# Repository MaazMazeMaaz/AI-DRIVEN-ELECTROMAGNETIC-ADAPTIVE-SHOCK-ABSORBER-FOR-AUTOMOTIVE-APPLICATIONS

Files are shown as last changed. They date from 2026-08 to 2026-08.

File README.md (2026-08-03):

# AI-Driven Electromagnetic Adaptive Shock Absorber for Automotive Applications

# Project Gallery

---

| Prototype | AI Detection |
| --- | --- |
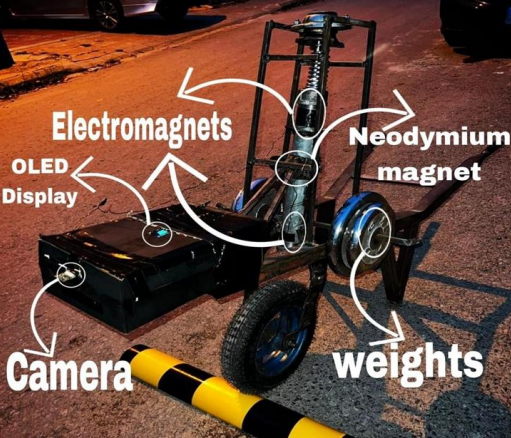
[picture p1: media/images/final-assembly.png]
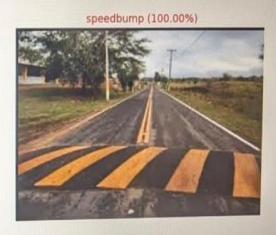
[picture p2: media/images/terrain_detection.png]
|  |  |

| CAD Model | Experimental Setup |
| --- | --- |
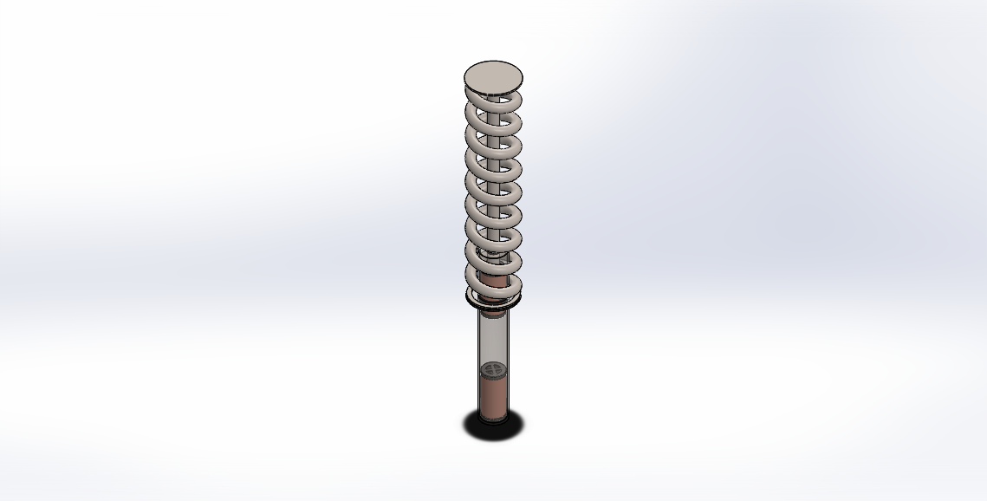
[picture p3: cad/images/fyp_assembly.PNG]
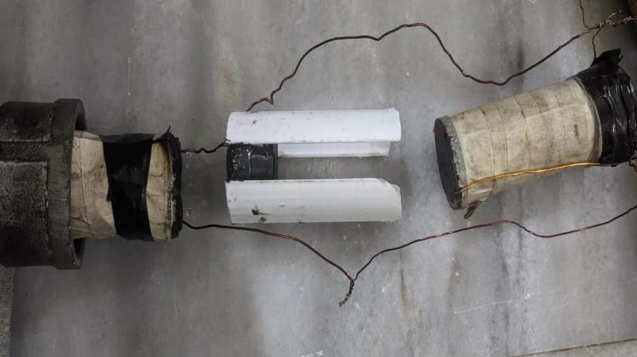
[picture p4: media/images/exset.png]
|  |  |

| Circuit Software | Experimental Circuit Hardware |
| --- | --- |
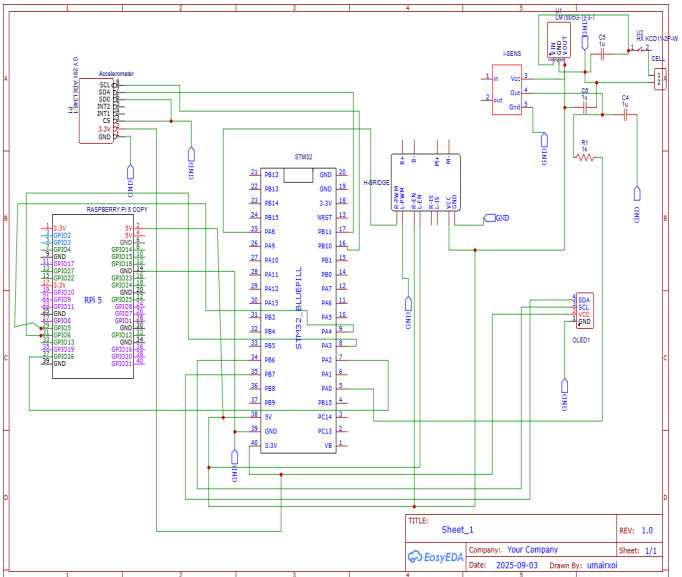
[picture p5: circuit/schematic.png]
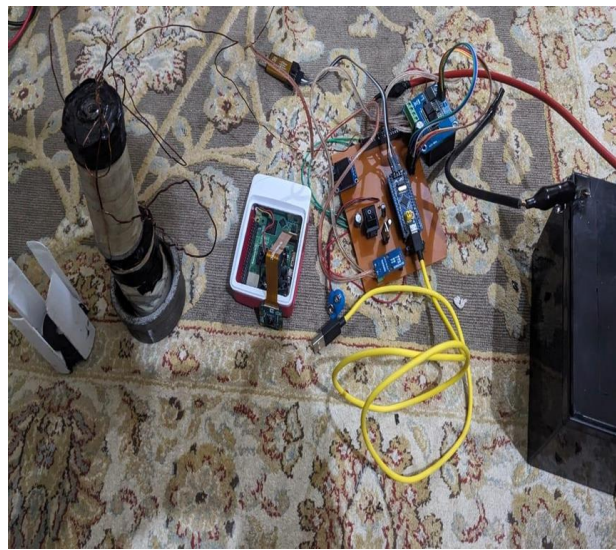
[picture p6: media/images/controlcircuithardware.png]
|  |  |
  










---

## Overview

Traditional hydraulic shock absorbers provide fixed damping characteristics regardless of road conditions, forcing engineers to compromise between ride comfort and vehicle handling. This project presents an **AI-driven electromagnetic adaptive shock absorber** capable of adjusting its damping characteristics in real time according to the terrain ahead.

The proposed system integrates computer vision, embedded control, electromagnetic actuation, and mathematical modelling into a single intelligent suspension framework. A Raspberry Pi 5 equipped with a camera performs real-time terrain classification using a trained YOLOv8 model. The detected terrain class is transmitted to an STM32F103 microcontroller, which dynamically regulates the current supplied to custom-designed electromagnets. The varying magnetic force modifies the damping characteristics of the suspension, enabling improved comfort and stability across different driving surfaces.

The project combines mechanical design, finite element simulation, artificial intelligence, embedded systems, and control engineering to demonstrate an adaptive suspension prototype suitable for future intelligent automotive systems.

---

## Key Features

* AI-based terrain classification using YOLOv8
* Real-time terrain recognition on Raspberry Pi 5
* Adaptive damping using electromagnets
* STM32-based embedded control system
* PWM current regulation through IBT-2 H-Bridge
* Closed-loop control using MPU6050 feedback
* Custom electromagnet design using MATLAB
* CAD modelling using SolidWorks
* Electromagnetic simulations using ANSYS Maxwell
* Modular hardware architecture for future automotive integration

---

## System Architecture

```
                Camera
                   │
                   ▼
        Raspberry Pi 5 (YOLOv8)
                   │
         Terrain Classification
                   │
               GPIO Signal
                   │
                   ▼
          STM32F103 Blue Pill
                   │
      PWM Current Control Logic
                   │
                   ▼
        BTS7960 / IBT-2 H-Bridge
                   │
                   ▼
        Electromagnetic Actuator
                   │
          Variable Damping Force
                   │
                   ▼
          Shock Absorber Assembly

          ▲
          │
 MPU6050 Accelerometer Feedback
```

---

## Project Objectives

The primary objectives of this project include:

* Develop an AI-based terrain classification system capable of recognizing asphalt, gravel, and speed bumps.
* Design an adaptive electromagnetic shock absorber capable of modifying damping characteristics in real time.
* Integrate computer vision with embedded control hardware.
* Develop mathematical models for electromagnet optimisation.
* Validate the proposed design using simulations and prototype testing.

---

## Technologies Used

### Artificial Intelligence

* YOLOv8 Classification
* Python
* OpenCV
* Ultralytics

### Embedded Systems

* Raspberry Pi 5
* STM32F103 Blue Pill
* UART Communication
* PWM Control

### Electronics

* BTS7960 (IBT-2) H-Bridge
* ACS712 Current Sensor
* MPU6050 Accelerometer
* LM7805 Voltage Regulator

### Mechanical Design

* Electromagnet Design
* Hydraulic Shock Absorber Modification
* Floating Permanent Magnet
* Custom Prototype Fabrication

### Engineering Software

* MATLAB
* SolidWorks
* ANSYS Maxwell
* Arduino IDE
* STM32CubeProgrammer

---

## Repository Structure

```
AI-Driven-Electromagnetic-Adaptive-Shock-Absorber
│
├── ai-terrain-classification/
│   ├── inference/
│   ├── training/
│   ├── results/
│   └──  best.pt
│
├── embedded/
│   ├── RaspberryPi/
│   └──  STM32/
│
├── matlab/
│
├── cad/
│
├── circuit/
│
├── modeling and simulations/
│
├── docs/
│
└── media/
```
---

# Hardware Components

| Component | Purpose |
| --- | --- |
| Raspberry Pi 5 | Runs the YOLOv8 terrain classification model |
| Raspberry Pi Camera V2 (8 MP) | Captures real-time road images |
| STM32F103 Blue Pill | Controls adaptive damping logic |
| IBT-2 (BTS7960) H-Bridge | Drives the electromagnets using PWM |
| ACS712 30A Current Sensor | Measures electromagnet current |
| MPU6050 Accelerometer | Provides stroke velocity and position feedback |
| LM7805 Voltage Regulator | Regulates power for electronics |
| 12V Battery | Main power source |
| Custom Electromagnets | Generate variable magnetic damping |
| Floating Neodymium Magnet | Provides repulsive magnetic force |
| Modified Shock Absorber | Mechanical suspension prototype |

---

# Software Stack

### Artificial Intelligence

* Python
* Ultralytics YOLOv8
* OpenCV
* NumPy

### Embedded Development

* Arduino IDE
* STM32 Arduino Core
* STM32CubeProgrammer

### Engineering Software

* MATLAB
* SolidWorks
* ANSYS Maxwell

---

# AI Terrain Classification

The perception module of the system is implemented on a **Raspberry Pi 5** using a YOLOv8 image classification model trained to recognize three road conditions:

* Asphalt
* Gravel
* Speed Bump

The Raspberry Pi continuously captures images from the Pi Camera and performs inference in real time. Once a terrain class is identified, the predicted class is transmitted  to the STM32 microcontroller.

Unlike conventional suspension systems that only react after encountering a disturbance, this approach enables **predictive damping control**, allowing the suspension to prepare before the vehicle reaches the detected terrain.

---

# Adaptive Damping Control

The STM32F103 Blue Pill serves as the real-time control unit.

After receiving the terrain classification from the Raspberry Pi, it adjusts the PWM duty cycle driving the BTS7960 H-Bridge.

Different terrains require different damping characteristics.

| Terrain | Control Strategy |
| --- | --- |
| Asphalt | Minimum or zero electromagnet current |
| Gravel | Medium current for moderate damping |
| Speed Bump | High current for maximum damping |

The MPU6050 accelerometer continuously measures piston movement and stroke velocity, allowing the controller to adjust damping dynamically during operation.

---

# Electromagnet Design

The damping mechanism replaces conventional passive damping with magnetic repulsion.

The prototype consists of:

* Two custom-designed electromagnets
* Soft iron cores
* Copper wire windings
* Floating neodymium magnet
* Hydraulic shock absorber body

Electromagnet dimensions were obtained through analytical calculations and optimized using MATLAB before validation in ANSYS Maxwell.

The final design balances:

* Magnetic force
* Current consumption
* Coil resistance
* Wire gauge
* Air gap
* Physical size constraints

---

# MATLAB Modelling

Several mathematical models were developed to optimize the electromagnet design, including:

* Magnetic force calculations
* Coil turn optimization
* Wire gauge selection
* Air-gap analysis
* Current limitation
* Saturation analysis
* Fringing correction
* Coil resistance estimation

MATLAB simulations were used to determine the optimum electromagnet geometry while satisfying mechanical constraints imposed by the modified shock absorber.

---

# ANSYS Maxwell Simulation

Finite Element Analysis (FEA) was performed using ANSYS Maxwell to validate the analytical calculations.

Simulation objectives included:

* Magnetic flux distribution
* Fringing effects
* Core saturation
* Field intensity
* Electromagnetic force validation

Simulation results closely matched the theoretical calculations and confirmed the suitability of the proposed electromagnet design.

---

# CAD Design

The complete suspension prototype was designed in SolidWorks.

The CAD model includes:

* Shock absorber cylinder
* Electromagnets
* Floating permanent magnet
* Mechanical spring
* Piston assembly
* Structural supports

The CAD model ensured correct fitment before fabrication and served as the basis for prototype manufacturing.

---

# Experimental Setup

The experimental platform consists of three primary subsystems.

### 1. Sensing

* Raspberry Pi 5
* Pi Camera

Responsible for real-time terrain perception.

---

### 2. Control

* STM32F103 Blue Pill
* MPU6050
* ACS712

Responsible for adaptive current regulation.

---

### 3. Actuation

* IBT-2 H-Bridge
* Electromagnets
* Floating Magnet
* Shock Absorber

Responsible for generating adaptive damping forces based on terrain classification.

---

# System Workflow

```text
Road Surface
      │
      ▼
Pi Camera
      │
      ▼
YOLOv8 Terrain Classification
      │
      ▼
GPIO Communication
      │
      ▼
STM32 Controller
      │
      ▼
PWM Current Generation
      │
      ▼
IBT-2 H-Bridge
      │
      ▼
Electromagnets
      │
      ▼
Adaptive Shock Absorber
      ▲
      │
MPU6050 Feedback
```
---

# Results

The developed prototype successfully demonstrated the feasibility of integrating artificial intelligence with an adaptive electromagnetic suspension system.

## AI Terrain Classification

The YOLOv8 terrain classification model was deployed on a Raspberry Pi 5 and achieved:

* **90% terrain classification accuracy**
* **Real-time inference at approximately 15 FPS**
* Recognition of three terrain classes:

  * Asphalt
  * Gravel
  * Speed Bump

The terrain information was transmitted to the STM32 controller with minimal latency, enabling predictive suspension control.

---

## Electromagnetic Suspension Performance

The prototype successfully demonstrated:

* Real-time adaptive damping
* Variable current control of electromagnets
* Stable communication between Raspberry Pi and STM32
* Closed-loop feedback using the MPU6050 accelerometer
* Successful integration of AI perception with embedded control

---

## Simulation Validation

The analytical MATLAB calculations were validated through ANSYS Maxwell simulations.

The simulation confirmed:

* Magnetic flux distribution
* Electromagnetic force generation
* Absence of significant magnetic core saturation
* Acceptable fringing characteristics

---

# Repository Contents

```text
📂 AI-Driven-Electromagnetic-Adaptive-Shock-Absorber

├── ai-terrain-classification/
│   ├── inference/
│   ├── training/
│   ├── results/
│   ├── best.pt
│   └── DATASET.md
│
├── embedded/
│   ├── RaspberryPi/
│   ├── STM32/
│   └── ESP32/
│
├── matlab/
│
├── cad/
│
├── circuit/
│
├── simulations/
│
├── calculations/
│
├── docs/
│
└── media/
```

---

# Dataset

The original training dataset is **not included** in this repository because of its large size.

The model was trained using three terrain categories:

* Asphalt
* Gravel
* Speed Bump

The repository includes:

* Trained model (`best.pt`)
* Training metrics
* Confusion matrices
* Validation results

Users may retrain the model using their own dataset organized in the same class structure.

---

# Future Improvements

Potential future enhancements include:

* Closed-loop PID or fuzzy logic control
* Magnetorheological (MR) fluid integration
* Optimized electromagnet geometry (E-core design)
* Thermal management for sustained high-current operation
* Expanded terrain classes (mud, sand, potholes, snow, wet roads)
* Real vehicle testing and validation

---

# Authors

**Final Year Project**

**Department of Mechatronics Engineering**

**Air University, Islamabad**

### Group Members

* Umair Mubashir
* Saad Bin Awais
* Muhammad Maaz

**Project Supervisor**

Dr. Rana Iqtidar Shakoor

---

# Acknowledgements

The authors would like to express their sincere gratitude to the Department of Mechatronics Engineering, Air University, Islamabad, for providing the facilities and academic environment necessary to complete this work.

Special thanks are extended to the project supervisor for continuous guidance and technical support throughout the development of this project.

---

# Citation

If you use this work in your research, please cite:

```text
Muhammad Maaz, Umair Mubashir, and Saad Bin Awais,
"AI-Driven Electromagnetic Adaptive Shock Absorber for Automotive Applications,"
Final Year Project,
Department of Mechatronics Engineering,
Air University, Islamabad,
2026.
```

---

# License

This project is licensed under the MIT License.

See the `LICENSE` file for details.

---

# Contact

For questions, suggestions, or collaboration opportunities, feel free to open an issue or submit a pull request.

---

## ⭐ If you found this repository useful, consider giving it a star!

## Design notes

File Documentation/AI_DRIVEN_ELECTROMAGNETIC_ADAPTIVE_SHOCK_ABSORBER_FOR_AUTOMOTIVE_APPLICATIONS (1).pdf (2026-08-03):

## AI DRIVEN ELECTROMAGNETIC ADAPTIVE SHOCK

## ABSORBER FOR AUTOMOTIVE APPLICATIONS

### Group Members:

Umair Mubashir | (221651)
Saad Bin Awais | (221654)
Muhammad Maaz | (221696)

BE MECHATRONICS (Session 2022-2026)

Project Supervisor

Dr. Rana Iqtidar Shakoor

Professor

DEPARTMENT OF MECHATRONICS ENGINEERING

FACULTY OF ENGINEERING

AIR UNIVERSITY, ISLAMABAD

ii

## AI DRIVEN ELECTROMAGNETIC ADAPTIVE SHOCK

## ABSORBER FOR AUTOMOTIVE APPLICATIONS

FINAL YEAR PROJECT REPORT

(SESSION 2022-2026)

DEPARTMENT OF MECHATRONICS

iii

## AI DRIVEN ELECTROMAGNETIC ADAPTIVE SHOCK

## ABSORBER FOR AUTOMOTIVE APPLICATIONS

### Submitted By:

Umair Mubashir | (221651)
Saad Bin Awais | (221654)
Muhammad Maaz | (221696)

Project Supervisor

Dr. Rana Iqtidar Shakoor

Professor

Chair Department

Dr. Noman Naseer

iv

Acknowledgments

Firstly we would like to thank Allah for giving us the opportunity to work on this project, all

praise is due to Allah and we are grateful. Secondly we would like to extend our utmost gratitude

to everyone who helped us throughout this project. We would like to thank our project

supervisor Dr Rana Iqtidar Shakoor for taking the time to meet with us and discuss the concerns

we had, we are grateful for his guidance. We would like to extend our gratitude with a special

thank you to our project co-supervisor Dr Hafiz Zia Ur Rehman, he has been helping us since

our 5

th semester, and without his guidance this project would not have been possible. Lastly we

would like to thank all our seniors who gave us their valuable time and attention to help us

overcome challenges during this project.

v

Abstract

Traditional shock absorbers have been used in vehicles for comfort and stability since the late 20th century. These shock absorbers provide fixed damping and are not capable of adapting to

different types of terrains. This project proposes a novel AI-driven electromagnetic adaptive

shock absorber which is capable of adjusting its damping in real time with the help of AI. The

damping of the shock absorber is dynamically adjusted with the help of electromagnetic forces

based on the type of terrain. The type of terrain is captured by a camera and identified using

computer vision techniques. Once the terrain is identified the controller regulates the current

flowing to the electromagnets which in turn varies the damping according to a predefined

control algorithm.

vi

Nomenclature

Symbol | Abbreviation

I

μ0

BgapB

Aeff

N

g

Current

Magnetic Permeability

Magnetic Flux Density (T)

Effective Area (m²)

Total Number Of Coil Turns

Air Gap (m)

vii

Table of Contents

1 | Introduction | 12
1.1 | Background and Motivation | 12
1.2 | Literature Review | 2
1.3 | Problem Statement | 4
1.4 | Objectives of the Project | 4
1.5 | Cost Analysis | 4
1.6 | Timeline of the Project | 6
1.7 | Work Division | 6
1.8 | Organization of Report | 7
2 | Description | 8
2.1 | Description of the Project | 8
2.2 | Methodology | 8
2.3 | Product Specifications | 10
2.4 | Preliminary Design and Calculations | 11
3 | Modeling and Simulation | 12
3.1 | Mathematical Modeling | 12
3.2 | Simulation Results | 15
3.3 | CAD Modeling | 16
3.4 | 3D Model Analysis | 17
3.5 | Algorithms | 18

viii

ix

List of Figures

x

List of Tables

## 1 Introduction

Shock absorbers are mechanical or hydraulic devices made for the damping of shocks in

vehicles. The main purpose of shock absorbers is as the name suggests absorbing the shock

induced and dissipating it as thermal energy. In the early 1900s vehicles were equipped

with leaf springs as shock absorbers. These leaf springs produced friction to produce a

damping effect by the damping was limited. In modern times most vehicular shock

absorbers are either twin-tube or mono-tube types. Mono-tube shock absorbers consists of

a singular tube with a piston and hydraulic fluid, the piston has different chambers or small

holes through which the hydraulic fluid moves when the piston is forced up or down due

to bumps, converting the shock into heat which must then be dissipated. Twin-tube shock

absorbers consists of two cylindrical tubes, an inner tube that is called the "working tube",

and an outer tube called the "reserve tube". They work similarly to mono-tube shock

absorbers.

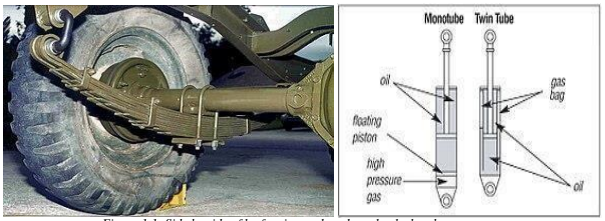
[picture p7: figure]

Figure 1.1: Side by side of leafspring and modern shock absorbers

Now comfort and stability are a big concern of the automotive industry and shock absorbers

have a massive role in both. Companies such as Delphi automotive and BOSE have

experimented with electromagnetic shock absorbers in the early 2000s, the shock absorbers

were made successfully and Delphi Automotive’s “Magneride” was commercialized as well,

but BOSE’s electromagnetic shock absorber never made it to market. In this project we are

going to take our own approach in developing an electromagnetic shock absorber which will

be adaptive as well using AI.

### 1.1 Background and Motivation

In recent years every industry including the automotive industry has been thinking of ways

2

Introduction

to improve both comfort and performance. A vehicles comfort and performance is highly

dependent on its suspension system, traditional shock absorbers have a fixed damping and

cannot be changed, and they can either provide a comfortable ride or a high performance

stable ride not both. With advancements in electromagnetism and AI creating a smart

solution for this is now possible. Our motivation stems from the demand of intelligent and

adaptive automotive systems for a more comfortable and high performing vehicle.

### 1.1.1 Sustainable Development Goals

This project contributes to Goal 9 of the UN Sustainable Development Goals which is to

build resilient infrastructure, promote inclusive and sustainable industrialization and

foster innovation. By innovating a new type of adaptive suspension system that is both

intelligent and versatile, this project contributes to the advancement of sustainable

transportation infrastructure and industrial innovation. Moreover the system enhances

comfort, performance, and safety across different terrains as well which supports Goal 11

(sustainable cities and communities) by promoting intelligent, adaptable, and resilient

transportation solutions.

### 1.2 Literature Review

In 2024 a group of engineers developed a small scale model based on electromagnetic shock

absorber, they integrated this small scale model with sensors for terrain recognition and

concluded that electromagnetic suspension systems provide superior ride comfort, handling,

and stability [1]. In 2020 a team of researchers implemented an energy-harvesting based

electromagnetic tuned mass damper (TMD) to be implemented in electric vehicles. A full

vehicle suspension model with four TMDs was created to simultaneously enhance the car

comfort and road-holding responses with a corresponding large-scale energy harvesting [2].

In 2017 according to a research on electromagnetic regenerative dampers, the study

concluded that electromagnetic regenerative dampers can provide better ride comfort than

conventional hydraulic dampers and the use of a mechanical motion rectifier can further

improve the ride comfort and road-handling performance of electromagnetic regenerative

dampers [3]. In an older study conducted in 2001 a passive suspension system for ground

vehicles based on a flexible electromagnetic shock absorber (EMSA) was designed, the

EMSA system is intended to be a low-cost and controllable passive suspension system for

ground vehicles[4]. Other than [1] one other research implemented terrain detection and even

that was made on a smaller prototype scale this. Without terrain recognition the systems are

passive at best. To achieve optimal comfort and performance we must have an active system,

3

AI DRIVEN ELECTROMAGNETIC ADAPTIVE SHOCK

ABSORBER FOR AUTOMOTIVE APPLICATIONS

capable of recognizing its surroundings and adapting itself to them. In 2021 a study was

conducted on terrain classification and assessment framework that uses both visual and

vibration data to classify terrain and predict its physical properties, with the system adapting

to changes in terrain over time which achieved 92% accuracy in classifying terrain using

visual data and 76% accuracy in predicting the physical properties of the terrain [5]. In 2021

evaluation of the accuracy of different YOLO models for real-time pothole detection was

done, finding that YOLOv4-tiny performs best [6].

In 2012, a study on the design and analysis of shock absorbers emphasized the performance

of structural and modal analysis alongside mechanical spring optimization [7]. Furthermore,

electromagnetic alternatives were compared to conventional hydraulic systems in 2006 and

2011, where the shock absorber designs using DC-brushless motors and resistive loads were

proposed to regulate damping force [8], [9]. Additionally, in 2016 a parametric study on

magnetorheological (MR) fluid based shock absorbers was conducted to analyze the

influence of control factors under steady-state and transient conditions [10]. Moreover, the

optimization of electromagnetic devices for physically constrained spaces in vehicle

suspension systems were studied in 2009 and 2013, optimizing magnetorheological (MR)

shock absorbers, utilizing finite element analysis to maximize damping force within specific

volume constraints [11], [12]. In 2015, an eight-pole electromagnetic bearing’s optimization

was presented, which aimed to maximize magnetic levitation force while comprehensively

considering copper and iron losses [13]. In 2022, a compact electromagnetic shock absorber

designed for motorcycles was looked into, this study analyzed parameters such as slot-pole

combinations and permanent magnet structures to achieve the required power output [14]. A

common theme across these investigations is the balance of core dimensions, winding space,

and required ampere-turn to generate target magnetic forces within strict physical

boundaries, which is typically addressed using finite element analysis and parametric

modeling techniques [11]–[14]

Magnetic fringing is a big problem, reducing magnetic fringing effects in electromagnetic

systems has several effective design modifications which could be used. In 2018, it was

demonstrated that modifying the air gap width and relocating the air gaps in tape-wound

amorphous cores can significantly reduce fringing flux effects [15]. In 2003, a low-fringing-

field magnetic bearing was developed using parallel opposing multipole placement,

achieving field attenuation from radius⁻³ to radius⁻¹⁰ [16]. Furthermore, in 2017, two simple

modifications for radial magnetic systems were proposed: adding permanent magnets to

4

Introduction

outer yokes and reducing outer yoke height [17]. Additionally, in 2009, a study showed that

incorporating fringing permeances into magnetic equivalent circuit models significantly

improves modeling accuracy, reducing force and flux errors by 67% and 88%, respectively,

compared to traditional methods [18]. Using all these previous studies we aim to design and

develop an AI driven electromagnetic adaptive shock absorber.

### 1.3 Problem Statement

Traditional shock absorbers have a specific damping which cannot be changed. Off-road

vehicles have robust shocks to handle rough terrains, whereas luxury cars consist of softer

shocks which make the ride comfortable. This fixed and specific nature of traditional shock

absorbers limits possibilities for automobiles, vehicles made for rough terrains and high

speeds compromise a comfortable ride for performance and other road vehicles compromise

performance for comfort. To address this issue we propose an innovative AI driven

electromagnetic adaptive shock absorber, this shock absorber with the help of

electromagnetic forces and real-time terrain monitoring can adjust its damping based on the

terrain. Previous electromagnetic shock absorber systems which had been introduced have

since not been in production, nor do they have the capability of terrain detection to accurately

identify and adapt the damping.

### 1.4 Objectives of the Project

### 1. Terrain Detection: Develop an AI-based system using machine learning to

accurately identify and differentiate between asphalt, gravel, and speed bumps.

### 2. Adaptive Damping: Design and implement an electromagnetic shock absorber

with real time adaptive damping based on detected terrain type.

### 3. System Validation: Integrate the shock absorber into a non-motorized test rig with

a single front-wheel suspension and evaluate its performance through controlled

experiments on different terrains.

### 1.5 Cost Analysis

The estimated cost of developing the prototype is approximately PKR 84,590, covering the major

hardware, electronic components, sensors, and fabrication materials required for implementation.

5

AI DRIVEN ELECTROMAGNETIC ADAPTIVE SHOCK

ABSORBER FOR AUTOMOTIVE APPLICATIONS

Table 1.1: Cost analysis

| Components | Cost (in PKR)
1. Pi 5 module + Original compatible | adapter 2.5k + Original Pi Casing which includes Heat sink and fan + Pi 5 camera module (V2 8MP) + SD card | 37,800
2. | STM32F103 Blue Pill ARM Cortex-M3 | 650
3. | LM7805 Voltage Regulator | 140
4. ACS712 30A 30 Amp Current Sensor | Module | 300
5. | IBT-2 43A H-bridge Double BTS7960 | 1,500
6. | Copper Wire | 7,700
7. | Miscellaneous Components | ~10,000
8. | Shock Absorber | 6,550
9. | Neodymium Magnet | 1,500
10. | MPU6050 Accelerometer | 450
11. | Battery | 5,500
12. | Test Rig | 11,300

6

Introduction

13. | Spring | 450
14. | Hydraulic Fluid | 750
| | Total= ~ 84,590

### 1.6 Timeline of the Project

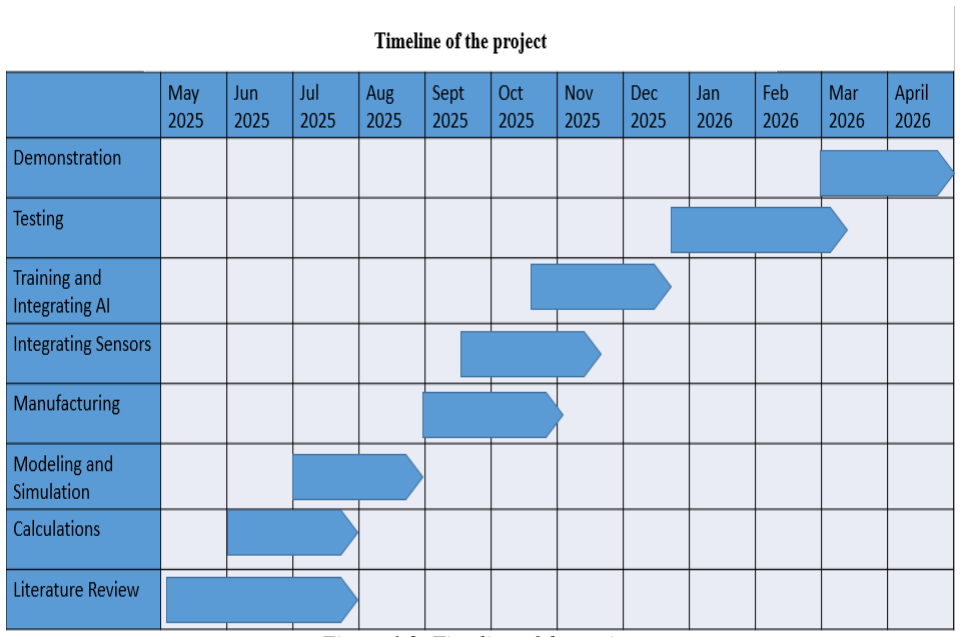
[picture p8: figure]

Figure 1.2: Timeline of the project.

### 1.7 Work Division

Table 1.2: Work division

Name | Roll number | Designation | Tasks
Umair Mubashir | 221651 | Electronics lead | • Electrical modeling. • Sensor analysis. • Design and fabrication of electronic circuitry.

7

AI DRIVEN ELECTROMAGNETIC ADAPTIVE SHOCK

ABSORBER FOR AUTOMOTIVE APPLICATIONS

Saad Bin Awais | 221654 | Team lead | • Mechanical calculations. • CAD. • Fabrication and assembly of mechanical components.
Muhammad Maaz | 221696 | Software lead | • Coding of controller. • Training AI model. • Integrating AI model with system.

### 1.8 Organization of Report

In chapter 1 of this report an in-depth introduction, background and motivation, timeline

as well as the objectives of this project are provided. Included in chapter 2 is a brief

description of the project along with the methodology and workflow of the project, some

initial calculations are performed as well.

## 2 Description

As discussed in the previous chapter the need for an adaptive shock absorber with real

time terrain monitoring is immense. In this chapter we will discuss how we will make

this project and what will this shock absorber consist of.

### 2.1 Description of the Project

The goal of this project is to design a shock absorber using electromagnetic repulsion

instead of a conventional spring damper system to enhance vehicle stability and

comfort. Damping will be dynamically adjusted through two electromagnets repelling

creating a damping force based on different terrains using terrain detection. Terrain

detection is implemented using classification techniques which will identify 3 different

terrains (asphalt, gravel, and speed bumps). The magnetism required to adjust the

damping will be controlled by current which is determined by the controller based on

predefined functions. To achieve this signal conditioning is necessary to allow a

smoother flow of current hence improving efficiency. Overall this system is an efficient

and responsive suspension system that can absorb shocks better than conventional

systems, especially on rough terrain.

### 2.2 Methodology

Block Diagram:

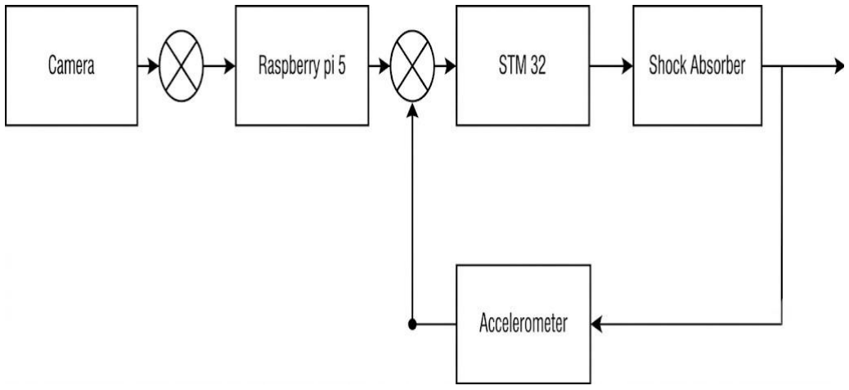
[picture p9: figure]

Figure 2.2: Block diagram.

9

AI DRIVEN ELECTROMAGNETIC ADAPTIVE SHOCK

ABSORBER FOR AUTOMOTIVE APPLICATIONS

The first block of the block diagram is a camera, this camera captures the terrain and sends

it to the controller. The controller then detects the type of terrain, then adjust the damping

of the shock absorber with the help of increasing or decreasing the current being supplied

to the electromagnets of the shock absorber as well as controlling the polarities of the

electromagnets. The accelerometer will then provide feedback to the controller about the

velocity and position of the piston, the controller will then bring back the piston to its

normal working position.

Flow chart:

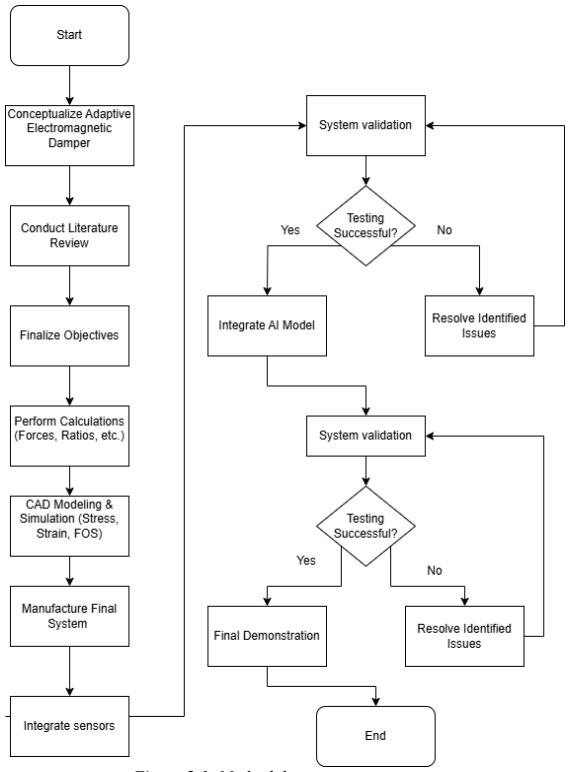
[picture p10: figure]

Figure 2.1: Methodology

10

Description

### 2.3 Product Specifications

This project consists of a spring damper based shock absorber. This shock absorber

unlike traditional shock absorbers has two electromagnets (or one electromagnet one

permanent magnet), one on the end of the plunger and one on the base. The cylinder is

filled with hydraulic fluid and the top of the plunger has a spring around it. The system

consists of a controller (raspberry pi) which controls the magnetic attraction and

repulsion forces to adjust the damping based on an AI terrain detection model. The

system is also equipped with a camera which is used for the terrain detection.

### 2.3.1 Schematic Diagram

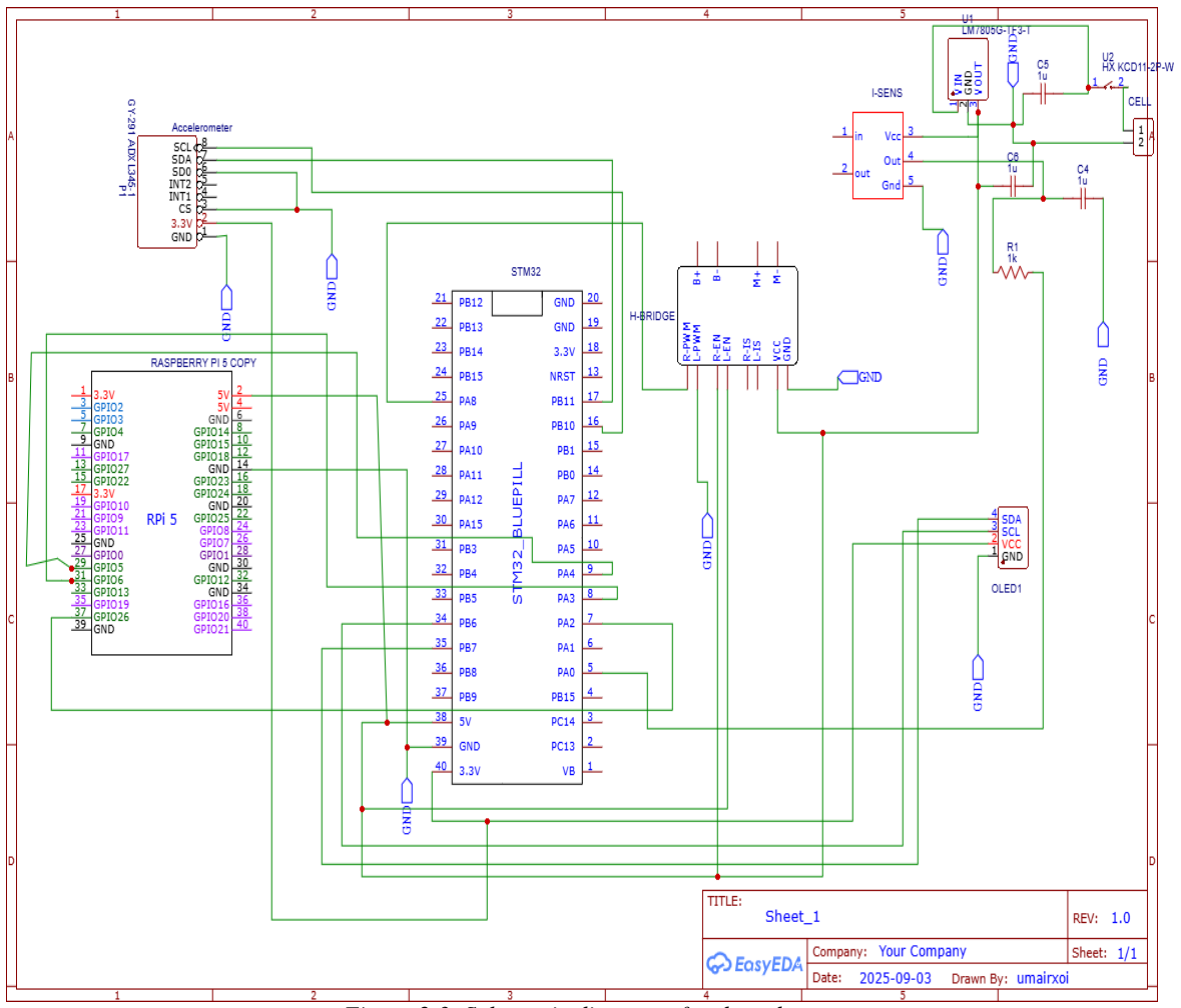
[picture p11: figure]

Figure 2.3: Schematic diagram of end product

11

AI DRIVEN ELECTROMAGNETIC ADAPTIVE SHOCK

ABSORBER FOR AUTOMOTIVE APPLICATIONS

### 2.4 Preliminary Design and Calculations

- Magnetic force between magnets:

F =

Bgap

2Aeff
2μ0
- Purpose: Calculates the repulsive force between the magnets across the air gap for a given flux.
- Variables:

BgapB: magnetic flux density (T), Aeff: effective area (m²), μ0 permeability of free space

- Constraints:

Outer Diameter <= 1.50 in, Height 3.00 in, DC Voltage= 12 V, Current Cap= 6 A cap, Air Gap=5

in

- Results:

Force = 3.6 N (0.37 kgf

## 3 Modeling and Simulation

This chapter walks through steps taken to build the AI-driven electromagnetic shock absorber. Its

goal: producing adaptive damping over a wide 5-inch space using magnetic fields. Terrain-sensing

artificial intelligence shapes how it responds, working alongside real-time data from sensors that

adjust output on the go.

### 3.1 Mathematical Modeling

- Magnetic force between magnets:

F =

Bgap

2Aeff
2μ0
- Purpose: Calculates the repulsive force between the magnets across the air gap for a

given flux.

- Variables:
- BgapB: magnetic flux density (T)
- Aeff: effective area (m²)
- μ0 permeability of free space
- Saturation-limited current

Isat =

Bsat (g +

lcore
μr

) Acore

μ0NAeff

- Purpose: Limits current so the core flux density does not exceed Bsat
- Variables:
- BsatB: saturation flux density (≈ 2.16 T)
- Acore= πr
2 = core cross-sectional area
- μ0= 4π×10−7 : permeability of free space
- N: total number of coil turns
- g: air gap (m)

13

- lcore: coil height

AI DRIVEN ELECTROMAGNETIC ADAPTIVE SHOCK

ABSORBER FOR AUTOMOTIVE APPLICATIONS

- Effective magnetic area (fringing correction)

Aeff = (rcore + αfringe. g)

2

- Purpose: Accounts for magnetic field spreading at the air gap (fringing).
- Variables:
- rcore: radius of the magnetic core (m)
- g: air gap length (m)
- αfringe: fringing factor (0.5 typical)
- Aeff: effective magnetic area (m²)
- Current from supply

I =

Rcoil
Vbat
- Purpose: Current that a 12 V battery would deliver if no other limits existed.
- Variables:
- Vbat: battery voltage (12 V)
- Rcoil: coil resistance (Ω)
- Number of turns

turns per layer =

ℎcoil
doverall

radiallayers =

router, max − rcore
doverall

N = radial layers ∗ turns per layer

- Purpose: Calculates total turns available given coil geometry.
- N = total number of turns
- hcoil = height of the coil (m)

14

Modeling and Simulation

- rcore = radius of the magnetic core (m)
- router,max = maximum allowed outer radius (m)
- doverall = overall wire diameter including insulation (m)
- turns_per_layer = number of turns in one vertical layer
- radial_layers = number of winding layers in the radial direction

Results:

--- Best overall (max force) --

-SWG 19 | Force = 3.6 N

(0.37 kgf)

Core radius = 0.30 in, Coil height = 2.96 in, OD = 1.13 in

Turns = 402, I=6.00 A, Rcoil=1.93 Ω, B_gap=0.024 T, Wire L = 27.7 m, Covering = Medium

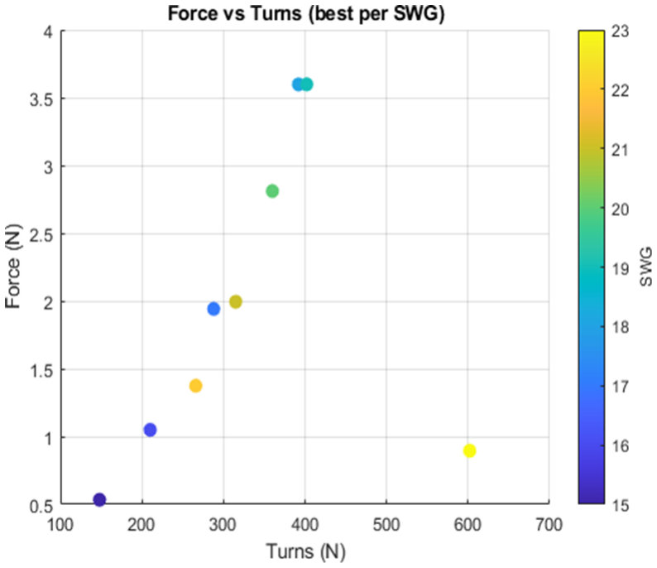
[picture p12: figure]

Figure 3.1: Force vs Turns

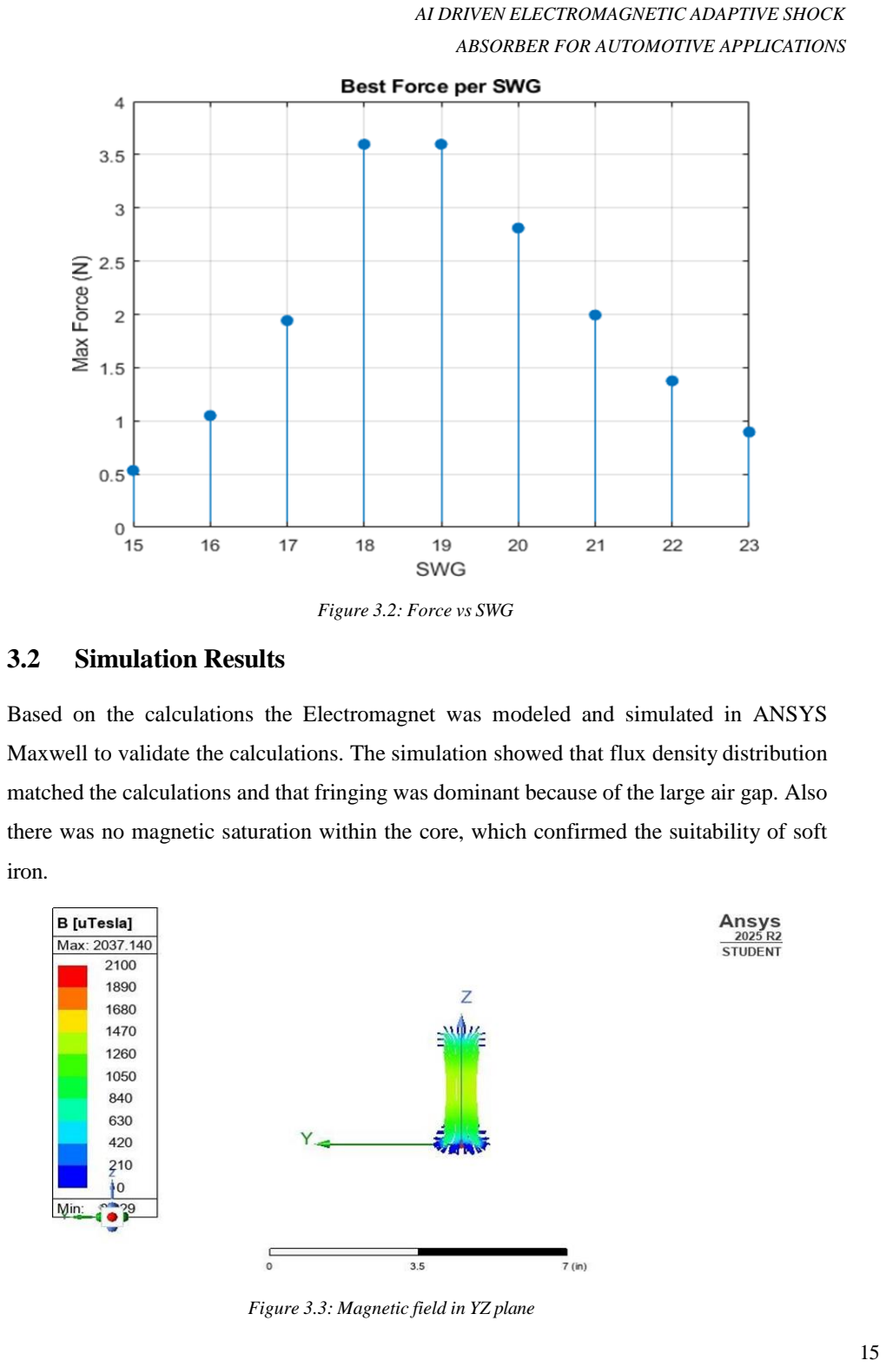
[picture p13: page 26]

15

AI DRIVEN ELECTROMAGNETIC ADAPTIVE SHOCK

ABSORBER FOR AUTOMOTIVE APPLICATIONS

Figure 3.2: Force vs SWG

### 3.2 Simulation Results

Based on the calculations the Electromagnet was modeled and simulated in ANSYS

Maxwell to validate the calculations. The simulation showed that flux density distribution

matched the calculations and that fringing was dominant because of the large air gap. Also

there was no magnetic saturation within the core, which confirmed the suitability of soft

iron.

Figure 3.3: Magnetic field in YZ plane

16

Modeling and Simulation

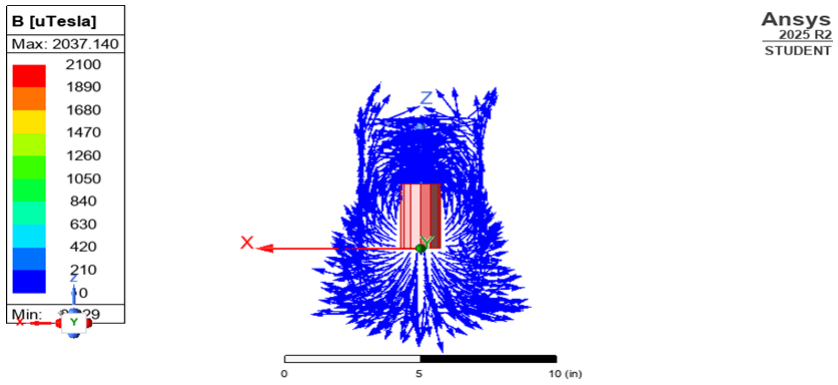
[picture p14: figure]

Figure 3.4: Magnetic field in XZ plane

### 3.3 CAD Modeling

The electromagnetic shock absorber was designed in Solidworks to ensure accurate

dimensions, and proper fitment inside the shock absorber cylinder. The CAD model

includes the electromagnets, cylinder, and mechanical spring. This model was made based

on the calculated dimensions obtained from MATLAB and physical constraints of the

shock absorber.

- CAD Model:

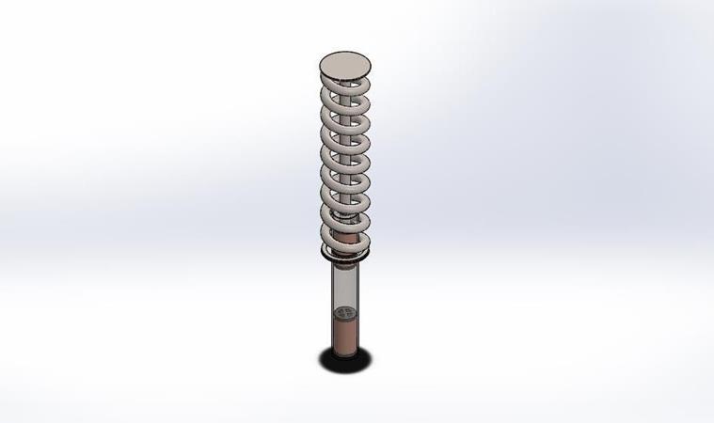
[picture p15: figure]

Figure 3.5: Complete CAD model

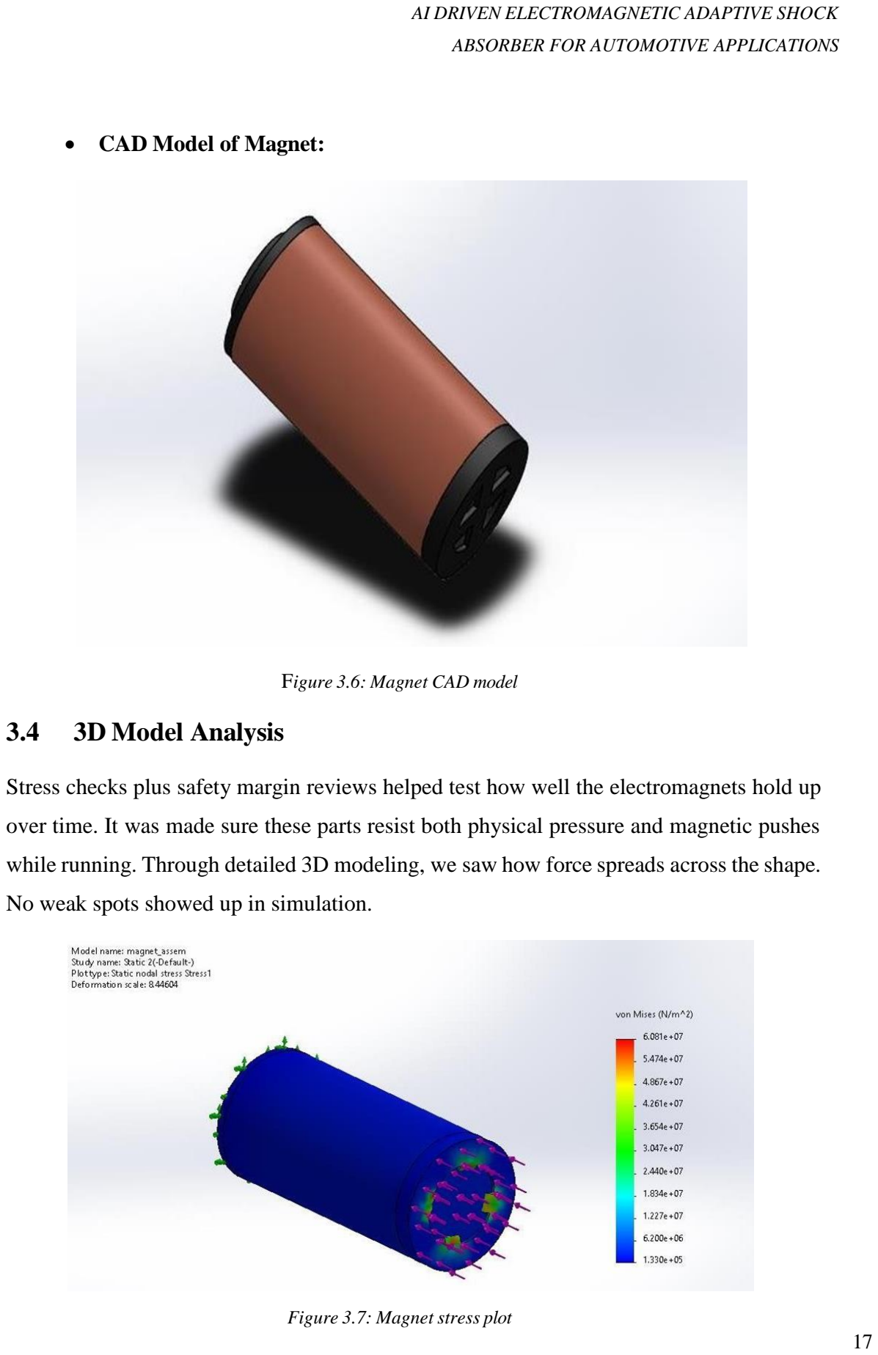
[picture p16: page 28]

17

AI DRIVEN ELECTROMAGNETIC ADAPTIVE SHOCK

ABSORBER FOR AUTOMOTIVE APPLICATIONS

- CAD Model of Magnet:

Figure 3.6: Magnet CAD model

3.4 3D Model Analysis

Stress checks plus safety margin reviews helped test how well the electromagnets hold up

over time. It was made sure these parts resist both physical pressure and magnetic pushes

while running. Through detailed 3D modeling, we saw how force spreads across the shape.

No weak spots showed up in simulation.

Figure 3.7: Magnet stress plot

18

Modeling and Simulation

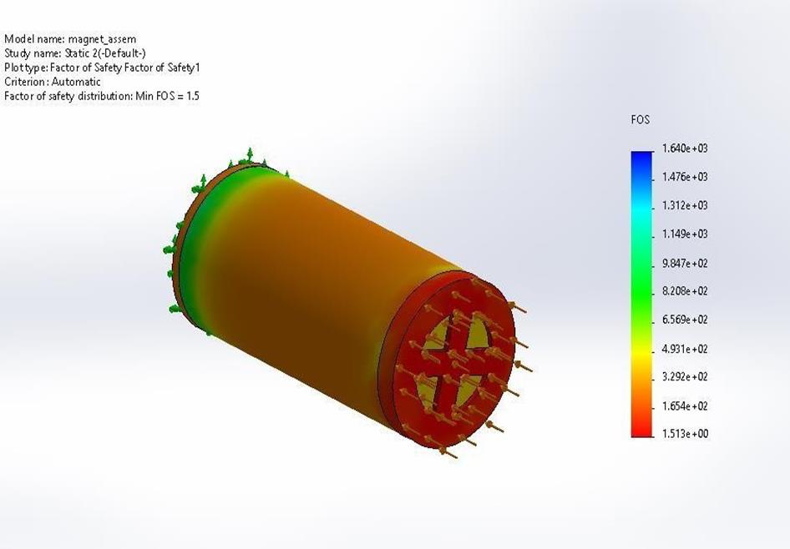
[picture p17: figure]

Figure 3.8: Magnet factor ofsafety

### 3.5 Algorithms

The control logic of the system is based on two algorithms: terrain classification and

adaptive damping regulation. The terrain classification algorithm runs on the Raspberry Pi

using a YOLO-based model trained to detect three types of road conditions, which are

asphalt, gravel, and speed bumps, from a camera acting as the sensor or input. Once a

terrain type is identified, the data gets sent to the STM32 microcontroller. The STM32 then

adjusts the current flowing through the electromagnet based on the detected terrain to

generate the desired repulsive force. An accelerometer is used in feedback which sends

position and stroke velocity data to the STM32 based on which damping is controlled.

These algorithms provide fast, terrain-aware, and adaptive control of the electromagnetic

shock absorber.

19

AI DRIVEN ELECTROMAGNETIC ADAPTIVE SHOCK

ABSORBER FOR AUTOMOTIVE APPLICATIONS

Figure 3.9: Speed bump detection results

Figure 3.10: Gravel detection results

20

Modeling and Simulation

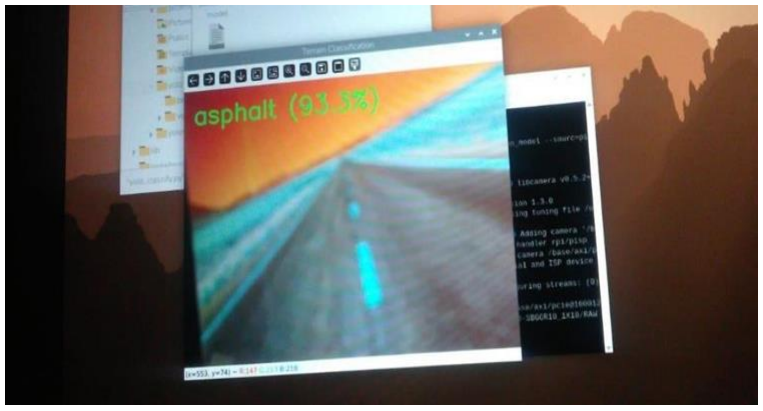
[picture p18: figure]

Figure 3.11: Asphalt detection results

### 3.5.1 Flowcharts

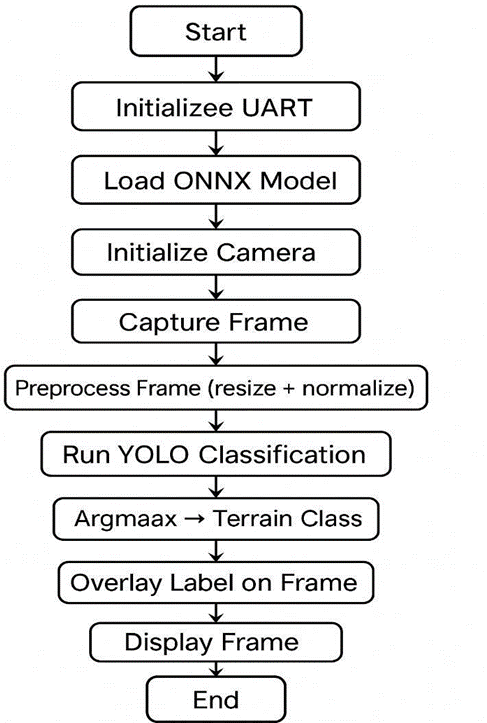
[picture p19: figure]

Figure 3.12: AI algorithm flow chart

## 4 Experimental Setup

The experimental setup is designed to evaluate the performance of the electromagnetic

shock absorber in a controlled environment before integrating it into rig. A transparent

plastic cylinder is fabricated to replicate the structure and internal dimensions of the

cylinder of the shock absorber. The electromagnets are attached at the base and piston, and

a floating neodymium magnet is positioned between them. By varying the current through

the electromagnet, different levels of repulsive force are generated, from which we can

observe the damping behavior, and stability.

### 4.1 Hardware Description

The hardware is divided into three blocks: sensing, control, and actuation. Raspberry Pi 5

acts as the sensing block, running the trained terrain-detection model and sending the data

to the STM-32. The STM32 acts as the control block, based on the detected terrain and

feedback received from the MPU6050 accelerometer it controls current using IBT-2 H-

Bridge. The electromagnet is powered by current from the 12V battery source. Supporting

electronics such as the ACS712 current sensor and LM7805 regulator ensure stable power

distribution and accurate measurement of current flow during testing.

### 4.1.1 Shock Absorber Modification and Core Dimension Derivation

An existing shock absorber was first purchased, the shock absorber was then opened, and

its cylinder diameter, and available vertical stroke were measured. These dimensions were

then used to determine the allowable size of the electromagnets, by which the maximum

core diameter, coil height, and permissible air gap were determined using analytical

calculations and MATLAB modelling. This helped in finding the optimal electromagnet

dimensions that would fit inside the shock absorber while still generating sufficient

magnetic repulsive force. Then after making some adjustments and modifications to

achieve desired results, a galvanized iron pipe of optimal dimensions was purchased and

then fabricated into a shock absorber.

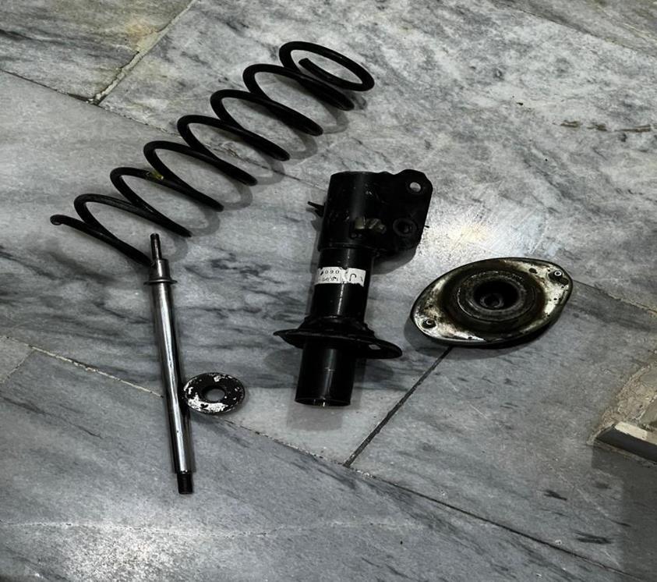
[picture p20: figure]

22

Experimental Setup

Figure 4.1: Purchased and modified existing shock absorber

### 4.1.2 Fabrication of Prototype Electromagnets

Before constructing the full-size electromagnet, a smaller prototype coil with fewer turns

was fabricated as a proof of concept and used to observe the behavior. After confirming

the feasibility, the actual electromagnet was constructed according to the calculated

dimensions. To obtain a suitable soft-iron core, strips of soft iron were extracted from an

old transformer and an electric fan. These strips were packed into a PVC pipe to form a

cylindrical core. Acrylic end-caps were then manufactured according to the required core

diameter and attached to secure the core in place and provide support to the winding. Then

21 SWG copper wire was carefully wound around the outer surface to form the coil. Later

the magnets were again redesigned with a 3D printed casing within which is the Iron core

and around it the copper wire has been wound. A floating magnet was introduced in

between the two electromagnets as well.

23

AI DRIVEN ELECTROMAGNETIC ADAPTIVE SHOCK

ABSORBER FOR AUTOMOTIVE APPLICATIONS

Figure 4.2: Experimental magnets

Figure 4.3: 2

nd Redesign

24

Experimental Setup

Figure 4.4: Actual electromagnets and floating magnet setup

### 4.1.3 Raspberry Pi 5 (Terrain Detection Unit)

The Raspberry Pi 5 functions as the sensing block of the system. It is equipped with a Pi Camera

(8MP), which continuously captures the forward view. Using data from the camera a YOLO based

machine-learning model detects the terrain type; speed bumps, gravel, and asphalt; and sends the

data to the STM32 through UART.

Figure 4.5: Raspberry pi 5 and camera

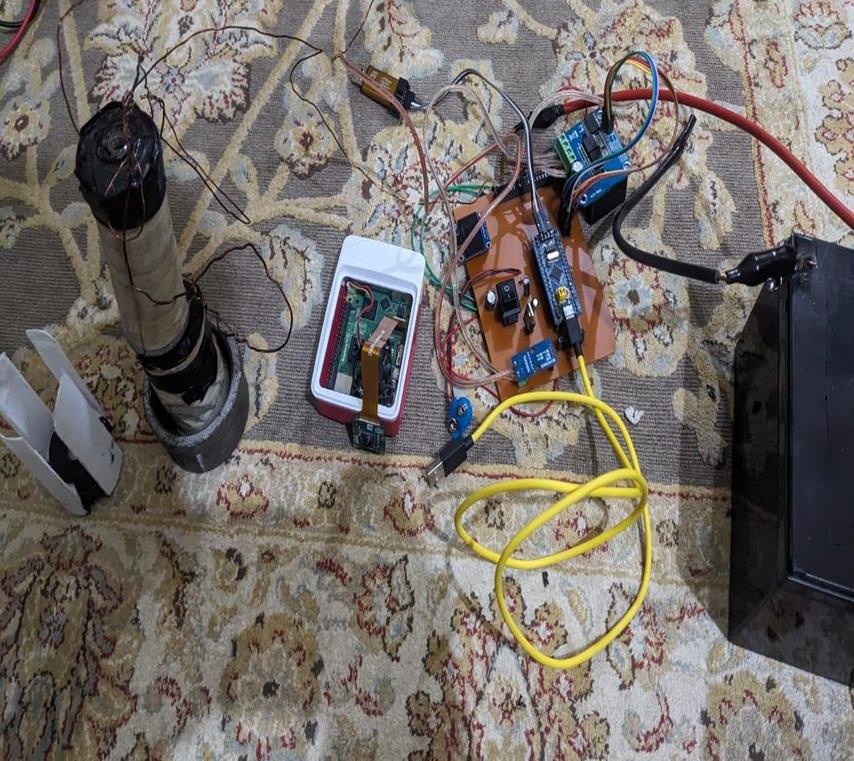
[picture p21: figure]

25

AI DRIVEN ELECTROMAGNETIC ADAPTIVE SHOCK

ABSORBER FOR AUTOMOTIVE APPLICATIONS

### 4.1.4 STM32 Control Circuit

The STM32F103 “Blue Pill” microcontroller controls the electromagnet’s current in real

time. It receives the terrain classification from the Raspberry Pi and PWM-modulates the

current through the IBT-2 H-bridge. An ACS712 current sensor is used to monitor the coil

current, and an MPU6050 accelerometer provides feedback on position and stroke velocity,

forming a closed-loop system that can adjust damping force.

Figure 4.6: STM32 control circuit

### 4.1.5 Final Electromagnetic Shock Absorber Assembly

Inside the shock absorber cylinder sits the full test arrangement. At the base, an

electromagnet is fixed; another connects directly to the moving piston. Between them, is a

floating neodymium magnet which is without restraint. Power circuits and the STM32 chip

controls current through the coils. From stroke details come through the accelerometer’s

readings. This entire unit later fits onto a one wheel testing frame built just for it.

Experimental Setup

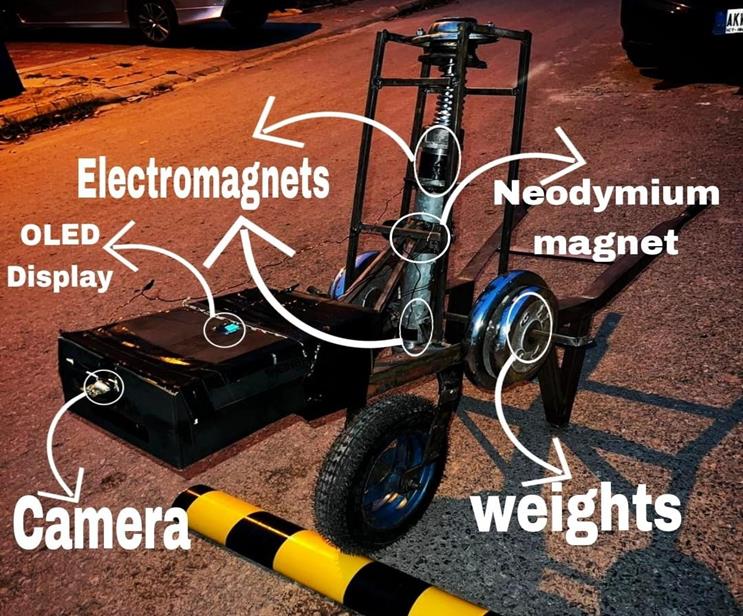
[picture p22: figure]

Figure 4.7: Final Electromagnetic Shock Absorber assembly

### 4.2 Components

- Raspberry Pi 5 module with original power adapter, heat-sink casing,

fan, and Pi Camera Module (8MP)

- STM32F103 Blue Pill ARM Cortex-M3 microcontroller
- ACS712 30A current sensor module
- IBT-2 H-Bridge with dual BTS7960 drivers for electromagnet

current control

- Custom soft-iron electromagnet core and Copper wire for coil winding
- Neodymium magnet
- MPU6050 accelerometer for feedback sensing
- 12V battery for powering electromagnet and electronic

26

## 5 Results and Discussion

Here's how well the smart shock absorber works. The testing focused on whether it could

distinguish between different terrain conditions. What counts is how fast the control system

responds. When there are shock changes, the electromagnets movement is examined. Real-

world motion reactions indicate performance. The quality of sensor feedback has a

significant impact on outcomes. Adjustments are made while driving, not after a halt. Each

trial was carried out without any predetermined patterns. Success is directly proportional to

the speed with which signals are processed. Surface texture causes a minor shift in the

results. In this setup, form follows function. Throughout the tests, feedback loops are always

running. Load variability reveals hidden delays. When the number of inputs increases, the

response time decreases.

### 5.1 Results

Pairing up the Raspberry Pi 5 with a YOLO-driven algorithm achieved 90% precision in

terrain recognition. While running live, it processed visuals at 15 fps because of this speed,

surface traits like different terrain conditions were spotted early enough for the controller to

adapt the damping to the detected terrain. The STM32F103 algorithm is as follows, when

moving across asphalt, current stays at zero. Hitting a speed bump triggered an early

electrical signal, preparing the coil to avoid delay, once the MPU6050 sensed sudden motion

from contact, power surged based on the stroke. Driven by stroke speed readings, the power

adjusted itself nonstop across gravel.

### 5.2 Discussion

It turns out the real-world tests backed up AI-controlled damping, even if some physical

quirks showed up. The metal pipe used as the shock cylinder, possibly stirs up unwanted

electrical noise that nudged the main magnetic push off track. Using a thinner 21 SWG

version winding in production raised resistance inside, making heat build fast in the coils.

The floating neodymium magnet showed some misalignment, especially tilting inside the

cylinder when repulsion spiked sharply. Even though the push generated was strong enough

for basic lab testing, keeping alignment steady stayed tricky due to stray fields and poor

centering. What made timing work well was an early activation method, which handled

delays between seeing a signal and the electromagnet reaching full strength.

Results and Discussion

### 5.3 Project Outcomes

A working model showed cameras plus motor controls can work together, adjusting wheels

on rough ground. This build proved sensors help machines react like living things when

roads change.

### 5.3.1 Project Impact

With smarter damping technology, transport systems gain adaptability where old mechanical

parts once failed. Instead of fixed setups, electromagnetic controls adjust on the go improving

ride quality and safety aligning with the UN SDG’s 9 and 11. Innovation like this feeds into

global progress, specifically targeting resilient infrastructure through fresh engineering

approaches.

28

## 6 Conclusions and Future Recommendations

### 6.1 Conclusions

The research conducted based on the stated objectives has been successfully concluded. The

following findings were derived from the development and testing of the prototype:

- A real-time terrain classification model was successfully deployed, achieving 90%

accuracy at 15 FPS on a Raspberry Pi 5.

- Electromagnetic actuators were fabricated and integrated into a shock absorber

assembly along with a floating permanent magnet, demonstrating variable damping

through current control.

- The velocity-based feedback with MPU6050 enabled dynamic response to physical

terrain disturbances.

- The project validated the combination of predictive visual data and reactive sensor

feedback for an effective adaptive suspension framework.

### 6.2 Future Recommendations

Based on the research conducted, the following future work is recommended for further

enhancement of the system’s performance and commercial viability:

1. Redesign of Electromagnet Geometry: It is recommended to transition from a cylindrical

coil to an E-shaped core configuration. This would provide a closed magnetic circuit,

reducing flux leakage and significantly increasing the force.

2. Magnetorheological (MR) Fluid Integration: Combining electromagnetic repulsion with

MR fluid would allow for higher damping forces and improved stability compared to a

purely air-gap based system.

3. Advanced Thermal Management: Implementation of active cooling systems or high-

temperature insulation would allow for sustained operation at higher current levels

without performance degradation.

30

Conclusions and Future Recommendations

4. Refined Control Algorithms: Future iterations should employ closed-loop PID or Fuzzy

Logic control to manage the stability of the floating magnet and provide smoother

damping transitions.

31

## Bibliography

[1] S. V, “MAGNO TUNE: ADVANCED ROAD SURFACE RECOGNITION &

EMS OPTIMIZATION,” INTERANTIONAL JOURNAL OF SCIENTIFIC

RESEARCH IN ENGINEERING AND MANAGEMENT, vol. 08, no. 05, pp.

1–5, May 2024, doi: 10.55041/ijsrem34121.

[2] S. Kopylov, Z. Chen, and M. a. A. Abdelkareem, “Implementation of an

electromagnetic regenerative tuned mass damper in a vehicle suspension

system,” IEEE Access, vol. 8, pp. 110153–110163, Jan. 2020, doi:

10.1109/access.2020.3002275.

[3] P. Li and L. Zuo, “Influences of the electromagnetic regenerative dampers on

the vehicle suspension performance,” Proceedings of the Institution of

Mechanical Engineers Part D Journal of Automobile Engineering, vol. 231, no.

3, pp. 383–394, Apr. 2016, doi: 10.1177/0954407016639503.

[4] S. Mirzaei, S. M. Saghaiannejad, V. Tahani, and M. Moallem, “Electromagnetic

shock absorber,” IEMDC, Nov. 2002, doi: 10.1109/iemdc.2001.939401.

[5] A. Kurup, S. Kysar, J. Bos, P. Jayakumar, and W. Smith, “Supervised Terrain

Classification with Adaptive Unsupervised Terrain Assessment,” SAE

International Journal of Advances and Current Practices in Mobility, vol. 3, no.

5, pp. 2337– 2344, Apr. 2021, doi: 10.4271/2021-01-0250.

[6] S.-S. Park, V.-T. Tran, and D.-E. Lee, “Application of various YOLO models

for computer Vision-Based Real-Time pothole detection,” Applied Sciences,

vol. 11, no. 23, p. 11229, Nov. 2021, doi: 10.3390/app112311229

32

Bibliography

[7] K. P. Kishore, "Design and analysis of shock absorber," International Journal

of Engineering Research and Applications, vol. 2, no. 4, pp. 2788–2795, 2012.

[8] N. Amati, G. Genta, and A. Tonoli, "Design and testing of an electromagnetic

shock absorber," in Proceedings of the 8th Biennial ASME Conference on

Engineering Systems Design and Analysis (ESDA2006), Torino, Italy, 2006,

Paper No. ESDA2006-95167, pp. 131–137.

[9] N. Amati, A. Festini, and A. Tonoli, "Design of electromagnetic shock

absorbers with brushless DC motors for automotive suspensions," IEEE/ASME

Transactions on Mechatronics, vol. 16, no. 5, pp. 912–921, Oct. 2011.

[10] J. Gołdasz and S. Dzierżek, "Parametric study of a magnetorheological shock

absorber under steady-state and transient conditions," Journal of Intelligent

Material Systems and Structures, vol. 27, no. 12, pp. 1673–1685, 2016.

[11] Q. H. Nguyen and S. B. Choi, "Optimal design of a magnetorheological shock

absorber for passenger vehicle using finite element analysis," Smart Materials

and Structures, vol. 18, no. 11, p. 115012, Oct. 2009.

[12] K. G. Sung and Y. J. Park, "Optimal design of a magnetorheological shock

absorber under specific volume constraints," Journal of Physics: Conference

Series, vol. 412, p. 012028, 2013.

[13] K. P. Lijesh and H. Hirani, "Optimization approach for an eight-pole

electromagnetic bearing considering copper and iron losses," Journal of

Vibration and Control, vol. 21, no. 12, pp. 2403–2414, 2015.

33

AI DRIVEN ELECTROMAGNETIC ADAPTIVE SHOCK

ABSORBER FOR AUTOMOTIVE APPLICATIONS

[14] Y. T. Tran, T. T. Nguyen, and M. Q. Nguyen, "Design and optimization of a

compact electromagnetic shock absorber for motorcycles," Actuators, vol. 11,

no. 3, p. 81, 2022.

[15] J. Walker, A. J. Forsyth, and R. A. McMahon, "Reducing fringing flux effects

in tape-wound amorphous cores through air gap modification," IEEE

Transactions on Power Electronics, vol. 33, no. 6, pp. 5241–5250, Jun. 2018.

[16] P. T. Konkola and D. L. Trumper, "Low-fringing-field magnetic bearing using

parallel opposing multipole placement," IEEE Transactions on Magnetics, vol.

39, no. 5, pp. 3121–3129, Sep. 2003.

[17] Y. Li and S. Schlamminger, "Modifications for lowering vertical magnetic

fields in radial magnetic yoke systems," IEEE Transactions on Instrumentation

and Measurement, vol. 66, no. 6, pp. 1530–1536, Jun. 2017.

[18] M. Batdorff and J. Lumkes, "Incorporating fringing permeances into magnetic

equivalent circuit models to improve force and flux predictions," Computers

and Electronics in Agriculture, vol. 68, no. 1, pp. 45–53, 2009.

ACADEMl.CX | Al WRlTlNG REPORT

# 10% detected as AI

The percentage indicatesthe combined amount oflikely Al-generated text as well as

likely Al-generated text that was also likely Al-paraphrased.

Important Notice

The percentage shown reflects a probabilistic assessment and should be treated as

an indicator, not a definitive conclusion. Results may vary depending on

writing style, subject matter, and documentstructure.

Always use thisreport as one ofseveral points ofreference rather than a sole

determining factor.

Guidelines

Thisreport analyzeslong-form writing,such as essays, dissertations, and articles.

Highlight colorsindicate likelihood of Al detection flagging:

cyan for high, light purple for moderate, unhighlighted for low.

Non-qualifying content (e.g. bullet points, annotated bibliographies, tables) is not

analyzed and may cause the highlighted text to differfrom the overall percentage

shown. lfthe document contains non-selectable text, scanned images, or other

formatting issues, the score may be inaccurate.

Details

Word Count: 5,759 Document

Size: 2.64 MB

Score Interpretation

0% - 1 9% | Low likelihood ofAl-generated content
20% - 50% | Moderate likelihood of Al-generated content
51 % - 1 00% | High likelihood of Al-generated content

Highlight Legend

High likelihood of being Flagged

Moderate likelihood of being flagged

Low likelihood of being flagged

Report generated: May 1 2, 2026 at 01 :1 8 PM UTC

Page 1 of 46

## 1ô% Overall Similarity

The combined total of all matches, including overlapping sources, for each database.

Match Groups

60 Not Cited or Quoted 1 2%

Matches with neither in-text citation nor quotation marks

3 Missing Quotations 1 %

Matchesthat are still very similar to source material

17 Missing Citation 3%

Matches that have quotation marks, but no in-text citation

0 Cited and Quoted 0%

Matches with in-text citation present, but no quotation marks

Top Sources

1 0% | Internet sources
7% | Publications
1 2% | Submitted works (Student Papers)

Match Groups

60 Not Cited or Quoted 1 2%

Matches with neither in-text citation nor quotation marks

3 Missing Quotations 1 %

Matchesthat are still very similar to source material

17 Missing Citation 3%

Matches that have quotation marks, but no in-text citation

0 Cited and Quoted 0%

Matches with in-text citation present, but no quotation marks

Top Sources

1 0% | Internet sources
7% | Publications
1 2% | Submitted works (Student Papers)

Top Sources

The sources with the highest number ofmatches within the submission. Overlapping sources will not be displayed.

www.researchgate.net | <1 %
www.coursehero.com | <1 %
repositorio.tec.mx | <1 %
telkomnika.uad.ac.id | <1 %
Yulin Liao, Donghong Ning, Haiping Du. IIninite horizon one-step MPC with linea... | <1 %
University of Western Sydney on 201 7-06-02 | <1 %

Publication

Student papers

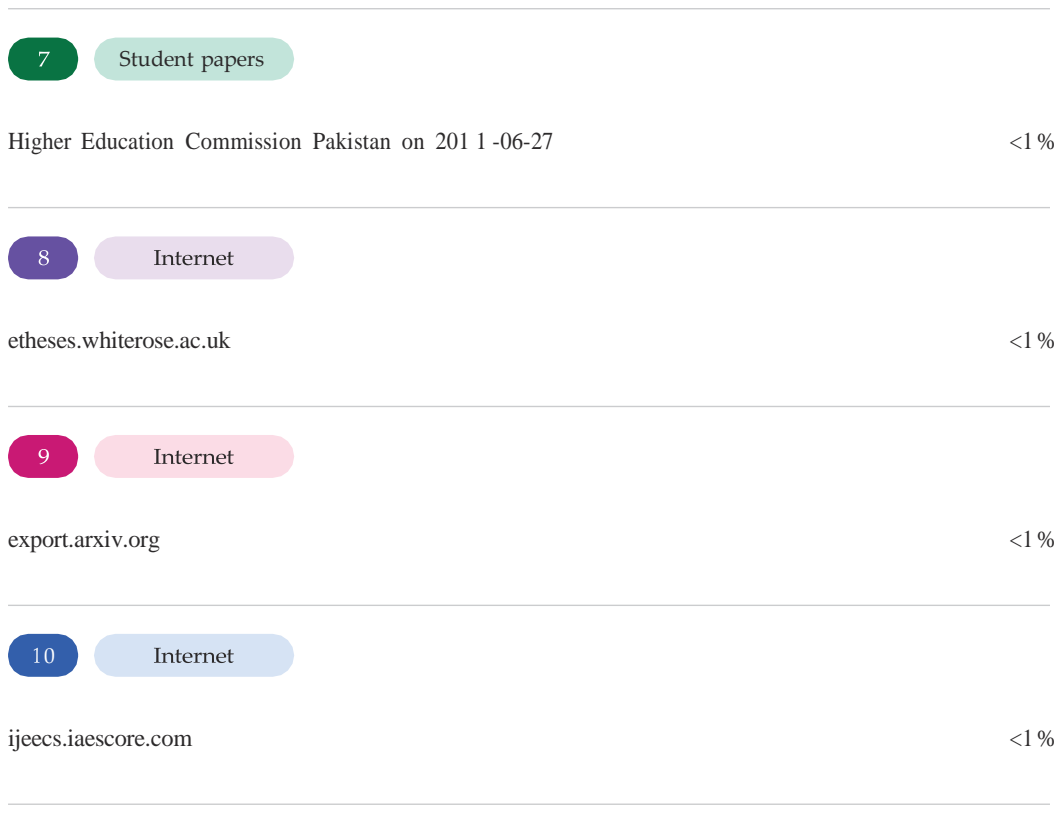
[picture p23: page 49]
Higher Education Commission Pakistan on 201 1 -06-27; etheses.whiterose.ac.uk; export.arxiv.org; ijeecs.iaescore.com; Student papers

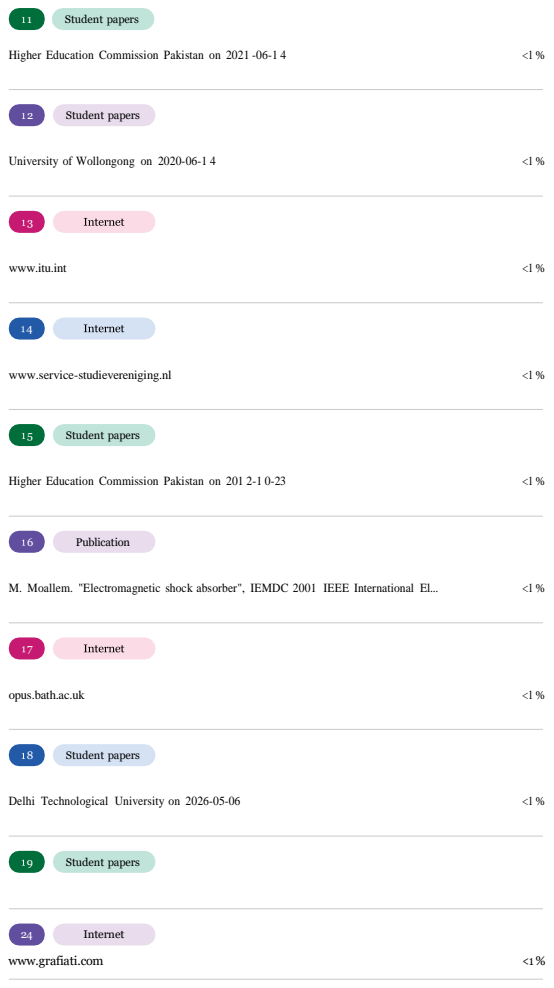
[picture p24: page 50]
Internet; www.grafiati.com; Higher Education Commission Pakistan on 2021 -06-1 4; University of Wollongong on 2020-06-1 4; www.itu.int; www.service-studievereniging.nl; Higher Education Commission Pakistan on 201 2-1 0-23; M. Moallem. "Electromagnetic shock absorber", IEMDC 2001 IEEE International El...; opus.bath.ac.uk; Delhi Technological University on 2026-05-06; Student papers; Publication

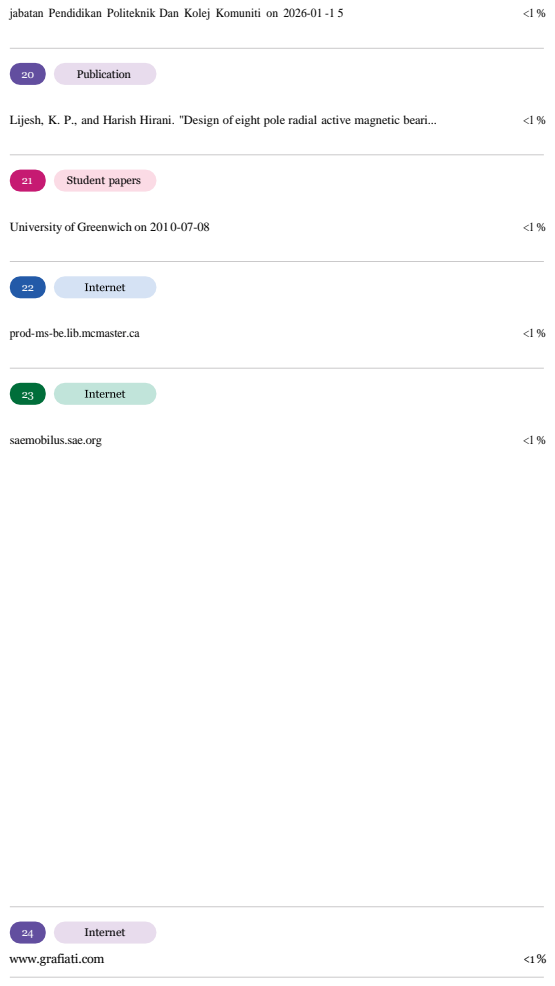
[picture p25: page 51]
Internet; www.grafiati.com; jabatan Pendidikan Politeknik Dan Kolej Komuniti on 2026-01 -1 5; Lijesh, K. P., and Harish Hirani. "Design of eight pole radial active magnetic beari...; University of Greenwich on 201 0-07-08; prod-ms-be.lib.mcmaster.ca; saemobilus.sae.org; Publication; Student papers

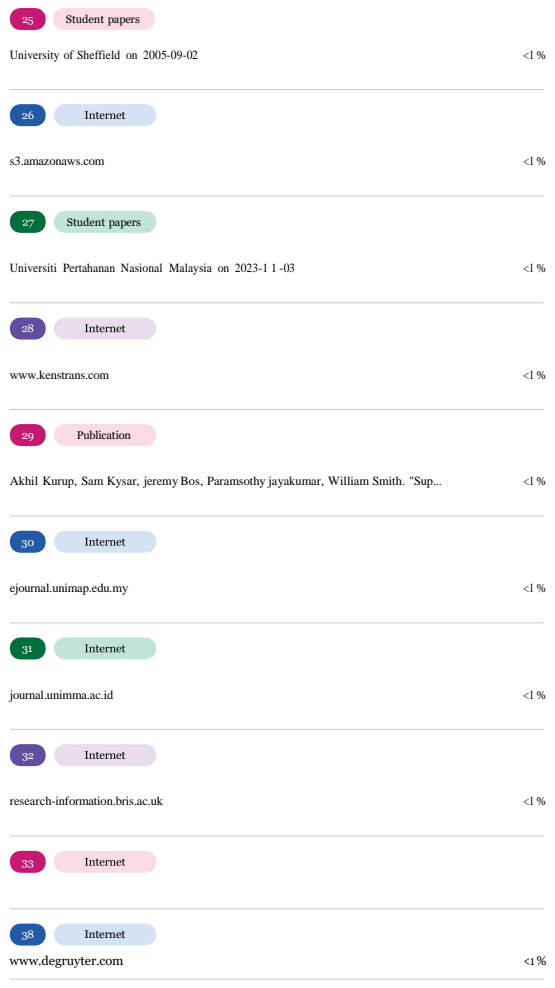
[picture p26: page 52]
Internet; www.degruyter.com; University of Sheffield on 2005-09-02; s3.amazonaws.com; Universiti Pertahanan Nasional Malaysia on 2023-1 1 -03; www.kenstrans.com; Akhil Kurup, Sam Kysar, jeremy Bos, Paramsothy jayakumar, William Smith. "Sup...; ejournal.unimap.edu.my; journal.unimma.ac.id; research-information.bris.ac.uk; Student papers; Publication

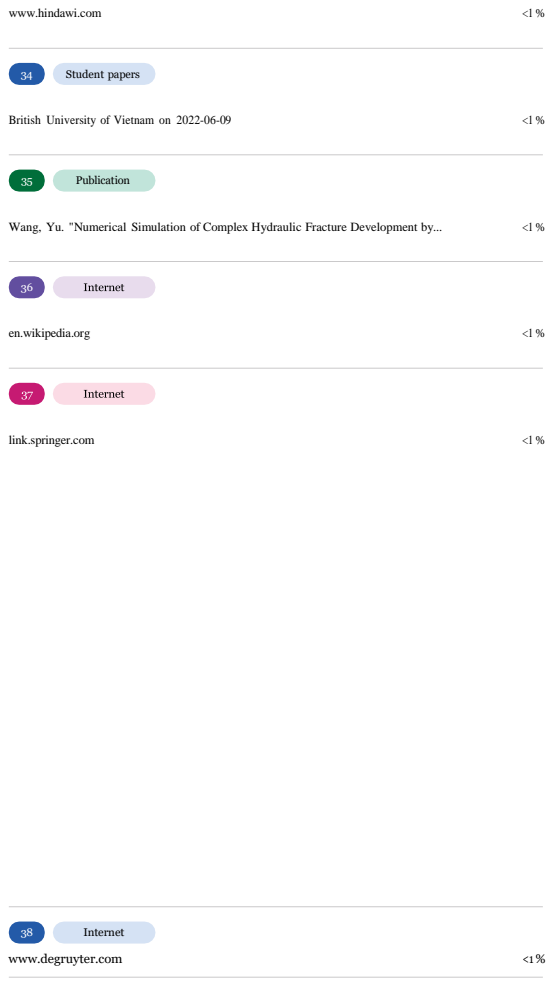
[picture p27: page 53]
Internet; www.degruyter.com; www.hindawi.com; British University of Vietnam on 2022-06-09; Wang, Yu. "Numerical Simulation of Complex Hydraulic Fracture Development by...; en.wikipedia.org; link.springer.com; Student papers; Publication

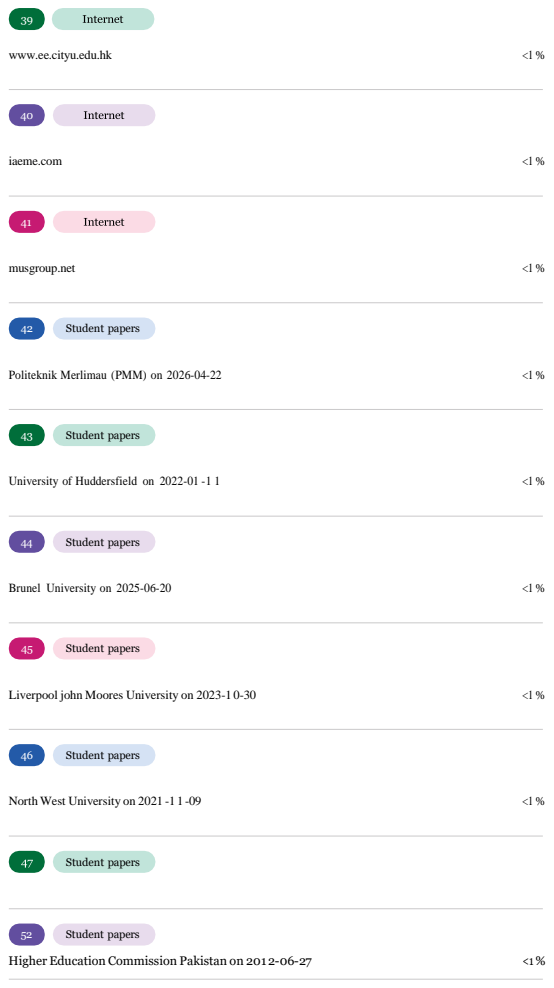
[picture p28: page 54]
Student papers; Higher Education Commission Pakistan on 2012-06-27; www.ee.cityu.edu.hk; iaeme.com; musgroup.net; Politeknik Merlimau (PMM) on 2026-04-22; University of Huddersfield on 2022-01 -1 1; Brunel University on 2025-06-20; Liverpool john Moores University on 2023-1 0-30; North West University on 2021 -1 1 -09

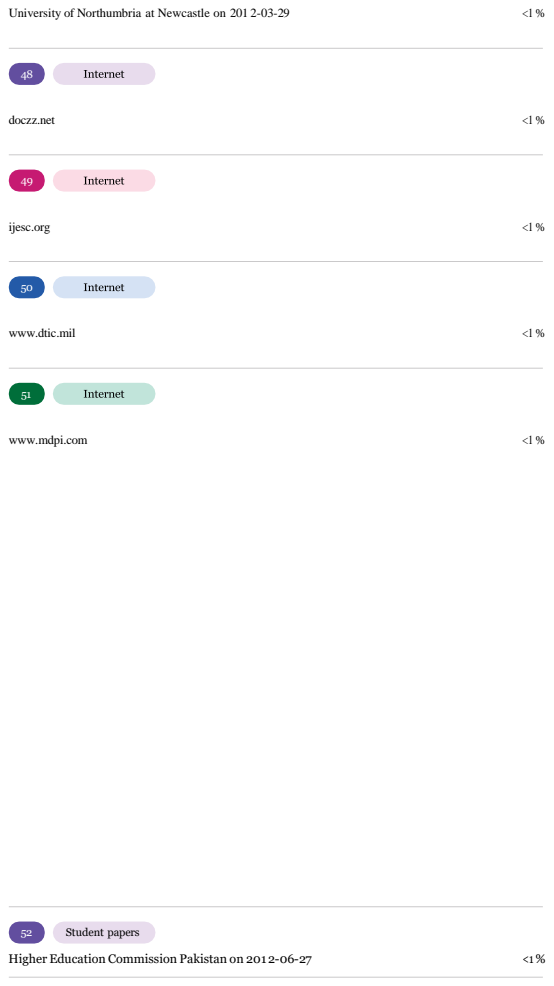
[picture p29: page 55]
Student papers; Higher Education Commission Pakistan on 2012-06-27; University of Northumbria at Newcastle on 201 2-03-29; doczz.net; ijesc.org; www.dtic.mil; www.mdpi.com

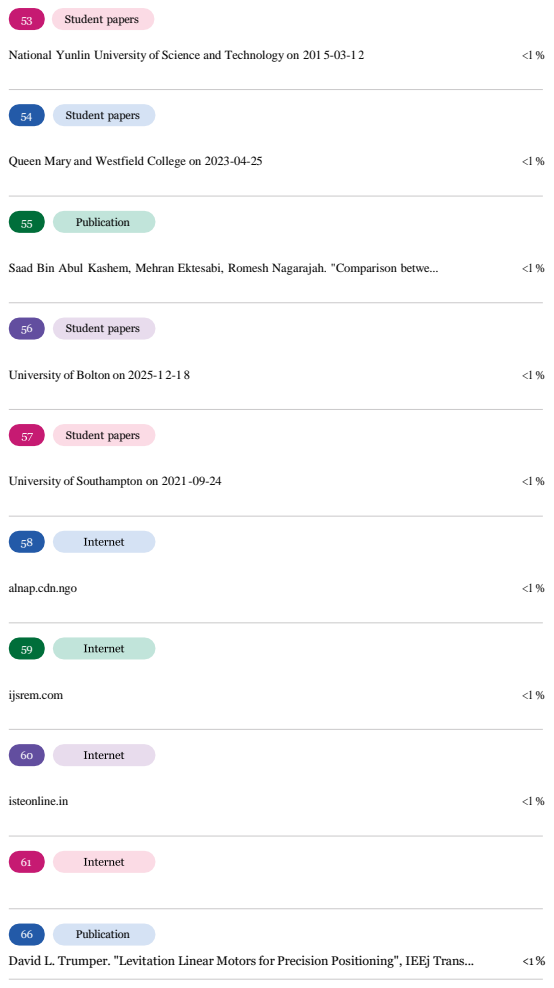
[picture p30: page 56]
Publication; David L. Trumper. "Levitation Linear Motors for Precision Positioning", IEEj Trans...; National Yunlin University of Science and Technology on 201 5-03-1 2; Queen Mary and Westfield College on 2023-04-25; Saad Bin Abul Kashem, Mehran Ektesabi, Romesh Nagarajah. "Comparison betwe...; University of Bolton on 2025-1 2-1 8; University of Southampton on 2021 -09-24; alnap.cdn.ngo; ijsrem.com; isteonline.in; Student papers

66 | Publication
David L. Trumper. "Levitation Linear Motors for Precision Positioning", IEEj Trans... | <1 %
www.slideshare.net | <1 %
King Faisal University on 2026-04-28 | <1 %
Quoc-Hung Nguyen. "Optimal design of MR shock absorber and application to ve... | <1 %
The University of Manchester on 201 6-09-1 2 | <1 %
"Proceedings of the FISITA 201 2 World Automotive Congress", Springer Science a... | <1 %
62 | Student papers
63 | Publication
64 | Student papers
65 | Publication

International Islamic University Malaysia on 201 5-07-07 | <1 %
UNICAF on 2026-04-01 | <1 %
67 | Student papers
68 | Student papers

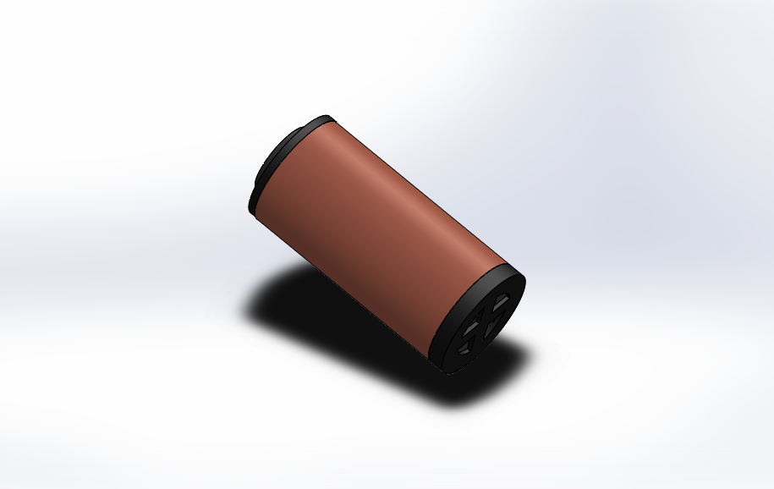
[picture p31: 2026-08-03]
cad/images/magnet_assem.PNG

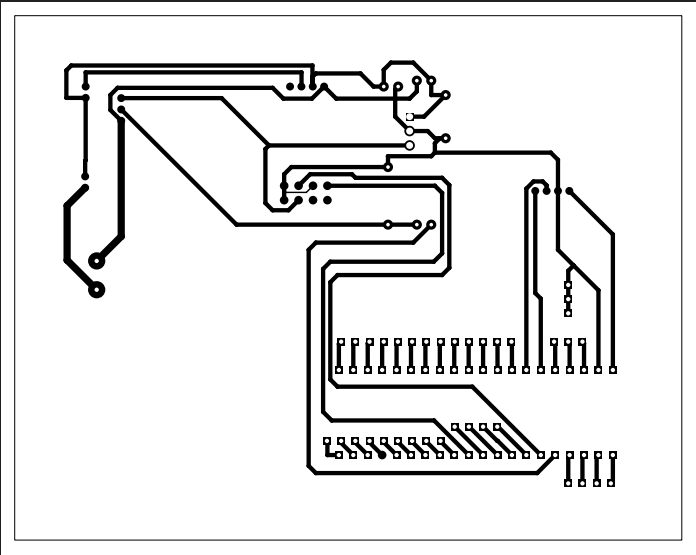
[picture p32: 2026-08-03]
circuit/pcb.png

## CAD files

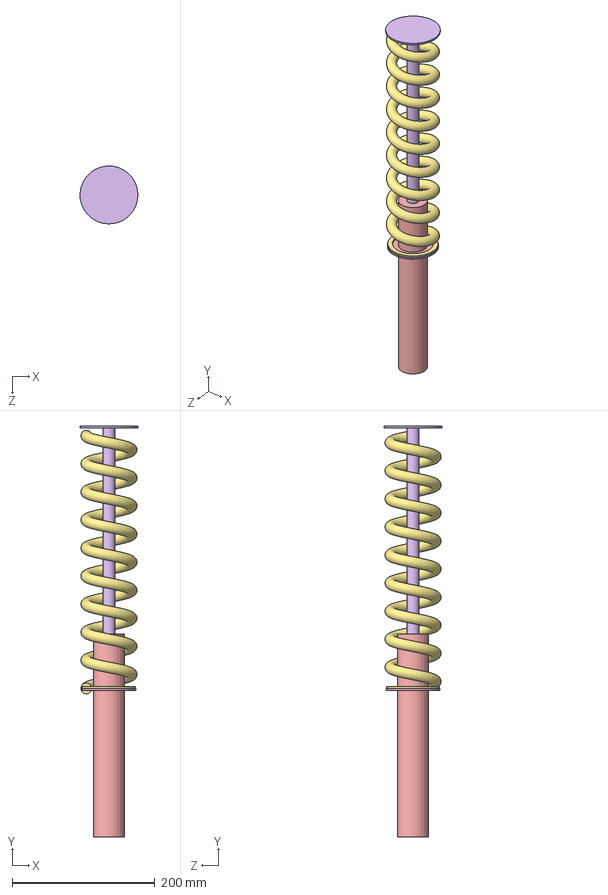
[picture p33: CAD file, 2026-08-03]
cad/solidworks/fyp_assembly.SLDASM
81.2 x 576.3 x 81.2 mm
coil x 2
iron_core x 2
jacket1 x 2
jacket2 x 2
shock_cylinder
shock_rod
spring

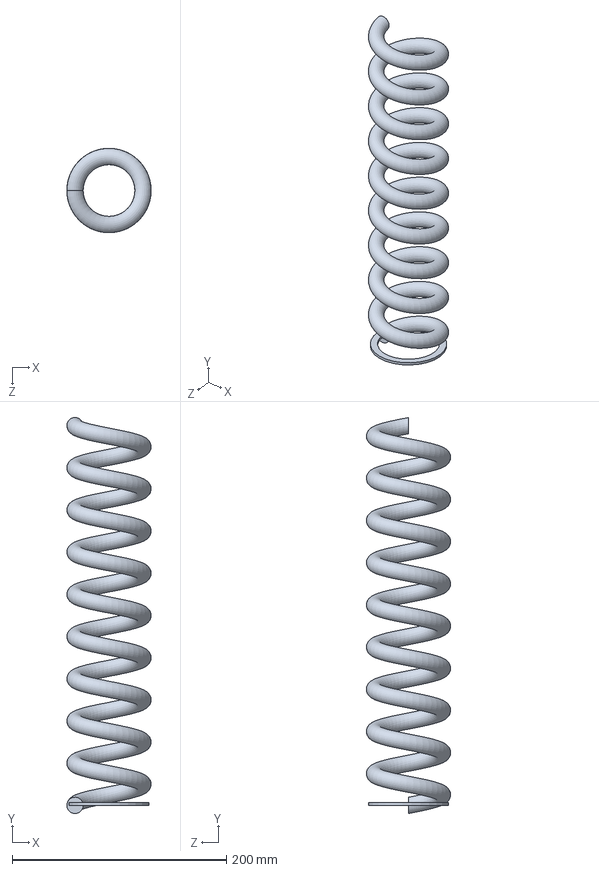
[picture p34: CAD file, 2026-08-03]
cad/solidworks/spring.SLDPRT
78.7 x 369.5 x 78.7 mm

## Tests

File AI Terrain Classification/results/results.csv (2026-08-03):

epoch | time | train/loss | metrics/accuracy_top1 | metrics/accuracy_top5 | val/loss | lr/pg0 | lr/pg1 | lr/pg2
1 | 166.711 | 0.58211 | 0.95238 | 1 | 0.2251 | 0.00044299 | 0.00044299 | 0.00044299
2 | 281.35 | 0.14796 | 1 | 1 | 0.02036 | 0.000882445 | 0.000882445 | 0.000882445
3 | 395.805 | 0.1244 | 1 | 1 | 0.00992 | 0.00130379 | 0.00130379 | 0.00130379
4 | 512.456 | 0.12365 | 0.96825 | 1 | 0.05642 | 0.00134412 | 0.00134412 | 0.00134412
5 | 640.505 | 0.08284 | 1 | 1 | 0.02297 | 0.00131582 | 0.00131582 | 0.00131582
6 | 765.156 | 0.07272 | 1 | 1 | 0.00421 | 0.00128753 | 0.00128753 | 0.00128753
7 | 882.134 | 0.07262 | 1 | 1 | 0.01104 | 0.00125923 | 0.00125923 | 0.00125923
8 | 997.343 | 0.06476 | 1 | 1 | 0.0069 | 0.00123094 | 0.00123094 | 0.00123094
9 | 1117.28 | 0.07962 | 1 | 1 | 0.01075 | 0.00120265 | 0.00120265 | 0.00120265
10 | 1234.26 | 0.08686 | 1 | 1 | 0.00158 | 0.00117435 | 0.00117435 | 0.00117435
11 | 1350.99 | 0.09393 | 1 | 1 | 0.00519 | 0.00114606 | 0.00114606 | 0.00114606
12 | 1465.89 | 0.07211 | 0.98413 | 1 | 0.02995 | 0.00111776 | 0.00111776 | 0.00111776
13 | 1592.24 | 0.05399 | 1 | 1 | 0.00084 | 0.00108947 | 0.00108947 | 0.00108947
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

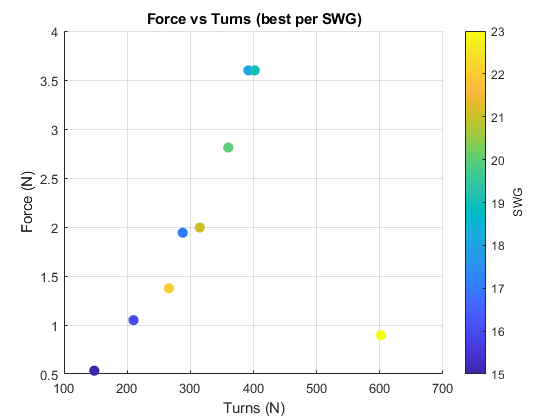
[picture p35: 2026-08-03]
modeling and simulations/matlab and ansys results/mat2.png

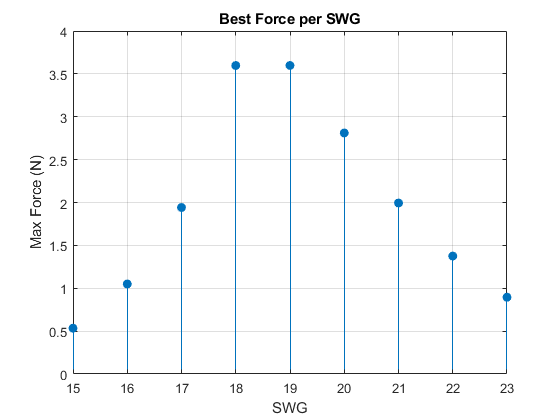
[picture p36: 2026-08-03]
modeling and simulations/matlab and ansys results/mat3.png

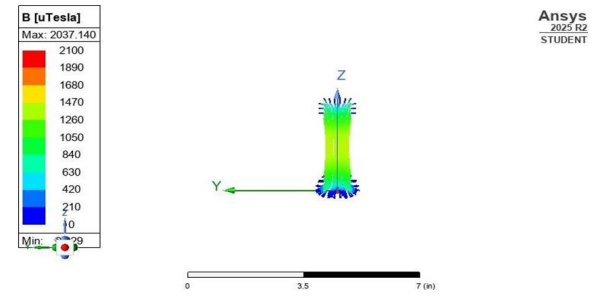
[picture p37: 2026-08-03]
modeling and simulations/matlab and ansys results/ansys1.png

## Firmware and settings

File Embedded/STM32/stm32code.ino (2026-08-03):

// Inputs from Raspberry Pi
const int asphaltPin = PA0;
const int gravelPin = PA1;
const int speedPin = PA2;

// PWM Output
const int pwmPin = PA8;

void setup()
{
    pinMode(asphaltPin, INPUT_PULLDOWN);
    pinMode(gravelPin, INPUT_PULLDOWN);
    pinMode(speedPin, INPUT_PULLDOWN);

    pinMode(pwmPin, PWM);

    analogWriteResolution(8);   // 0-255
}

void loop()
{
    bool asphalt = digitalRead(asphaltPin);
    bool gravel = digitalRead(gravelPin);
    bool speed = digitalRead(speedPin);

    if (asphalt)
    {
        // Lowest output
        analogWrite(pwmPin, 0);
    }

    else if (gravel)
    {
        // Medium output (~3 A after calibration)
        analogWrite(pwmPin, 128);
    }

    else if (speed)
    {
        // Maximum output
        analogWrite(pwmPin, 255);
    }

    else
    {
        // No terrain selected
        analogWrite(pwmPin, 0);
    }

    delay(5);
}

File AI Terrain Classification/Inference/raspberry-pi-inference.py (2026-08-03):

import cv2
from ultralytics import YOLO
from picamera2 import Picamera2

# Load your classification model
model = YOLO("best_ncnn_model", task="classify")

# Initialize Pi Camera
picam2 = Picamera2()
config = picam2.create_preview_configuration(main={"size": (640, 480)})
picam2.configure(config)
picam2.start()

print("Running... Press 'q' to quit")

while True:
    # Capture frame
    frame = picam2.capture_array()

    # Convert RGB -> BGR (important for OpenCV)
    frame = cv2.cvtColor(frame, cv2.COLOR_RGB2BGR)

    # Optional: resize for speed (uncomment if needed)
    # frame = cv2.resize(frame, (320, 320))

    # Run inference
    results = model(frame)

    probs = results[0].probs
    if probs is not None:
        class_id = probs.top1
        confidence = probs.top1conf.item()
        class_name = model.names[class_id]

        label = f"{class_name} ({confidence:.2f})"
        print(label)

        # Draw result on frame
        cv2.putText(frame, label, (20, 40),
                    cv2.FONT_HERSHEY_SIMPLEX, 1,
                    (0, 255, 0), 2)

    # Show output
    cv2.imshow("Terrain Classification", frame)

    if cv2.waitKey(1) & 0xFF == ord('q'):
        break

cv2.destroyAllWindows()
picam2.stop()

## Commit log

2026-08-03 uploading train.py
    Added code to mount Google Drive, install Ultralytics, unzip dataset, and train YOLO model for terrain classification.
2026-08-03 Implement terrain classification using YOLO on Raspberry Pi
    This script captures frames from the Raspberry Pi camera, runs inference using the YOLO model for terrain classification, and displays the results with confidence scores.
2026-08-03 Implement terrain classification with GPIO control
    This script captures images from a camera and classifies terrain types using a YOLO model, controlling GPIO outputs based on the classification results.
2026-08-03 Implement terrain-based PWM control for output
2026-08-03 Replace prototype image with final assembly
    Updated project gallery images to reflect final assembly.
2026-08-03 Add final assembly image to README
    Added an image of the final assembly to the README.
2026-08-03 Refine description of Raspberry Pi image capturing
    Removed 'through' from the description of the Raspberry Pi's functionality.
2026-08-03 Add project gallery to README
    Added a project gallery section with images and descriptions for various prototypes and setups.

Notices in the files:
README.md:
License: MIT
